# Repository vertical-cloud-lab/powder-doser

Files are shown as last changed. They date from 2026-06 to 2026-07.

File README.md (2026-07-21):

# powder-excavator

A pure-mechanical, gantry-mounted "ladle / trough" for picking up loose
powder from a bed and depositing it at a target location. The trough is
suspended between two vertical arms that grip its **two short end caps**;
a single **longitudinal pivot pin** runs through both end caps along the
trough's long axis L. There are no actuators on the bucket itself — the
gantry's existing X / Z motion plus a fixed wall-/post-mounted **smooth
inclined cam ramp** does all the work.

> **Geometry note (post-review).** An earlier revision of this design used
> a **transverse** pivot pin (running across the trough's width D) and
> tipped the trough **end-over-end** against a **sawtooth** ledge. Both
> choices were retired after a high-effort review by Edison Scientific
> identified (i) a kinematic impossibility — a fixed sawtooth tooth
> cannot engage a fixed-radius hook on a horizontally-translating pivot
> without the lip plunging through the tooth — and (ii) a severe trapped-
> volume / arching problem when cohesive powders are forced to bottleneck
> through the narrow ~13 mm spill point of an end-over-end half-cylinder.
> The current design uses a **longitudinal** pivot pin and **sideways
> tilt** so powder pours over the full 80 mm long edge, and replaces the
> sawtooth with a **smooth cam ramp** that the trough's chamfered bumper
> slides up. A follow-on hand sketch
> ([`PXL_20260423_231729467.jpg`](PXL_20260423_231729467.jpg)) refines the
> cam ramp into a **pin-defined-path** (peg-in-routed-slot) variant in
> which a peg on a stem hanging from the gantry is captured in a slot
> routed into a fixed external board, so the slot path deterministically
> programs the trough's tilt schedule. The full review and the verbatim
> Edison answers live in [`docs/edison/`](docs/edison/); the
> literature-aware brainstorming doc has been ported to a LaTeX manuscript
> with a proper BibTeX bibliography (see
> [`docs/manuscript/main.tex`](docs/manuscript/main.tex) and
> [`docs/manuscript/refs.bib`](docs/manuscript/refs.bib); build with
> `cd docs/manuscript && make`).

## Original concept sketch

Design sketch

## Hardware

Candidate parts for the auger drive motor, vibration motor, external
solenoid, and the Raspberry Pi Zero 2 W driver boards needed to
control them are documented in
[`hardware/vibration-motor-and-solenoid.md`](hardware/vibration-motor-and-solenoid.md).
## Cleaned-up design diagram

The sketch above has been recreated as four labelled subpanels. Each is a
self-contained SVG with its own caption. All four are produced (along with
the mechanism animation below) by a single reproducible script,
[`scripts/generate_figures.py`](scripts/generate_figures.py).

### Panel A — Orthographic views (end / side / top)

Panel A — orthographic

### Panel B — End-cap pivot detail

Panel B — pivot detail

### Panel C — 3D / isometric view of trough on gantry

Panel C — isometric

### Panel D — Mechanism of action (4 steps)

Panel D — mechanism of action

### Panel E — Pin-defined-path actuation variant

A follow-on hand sketch
([`PXL_20260423_231729467.jpg`](PXL_20260423_231729467.jpg)) refines the
smooth cam ramp into a peg-in-routed-slot mechanism. A vertical stem hangs
from the gantry carriage on a pin pivot; a transverse peg at the top of the
stem rides in a slot routed into a fixed external board. The slot's shape
over `X` deterministically programs the trough's tilt schedule, with the peg
captive in the slot for the entire stroke (no approach-and-contact
ambiguity, and bidirectional return without relying on gravity). See
[`docs/manuscript/main.tex`](docs/manuscript/main.tex) §"Pin-defined-path
actuation" for the full trade-off discussion.

Panel E — pin-defined-path actuation

### Animation — cam-engagement and sideways tilt

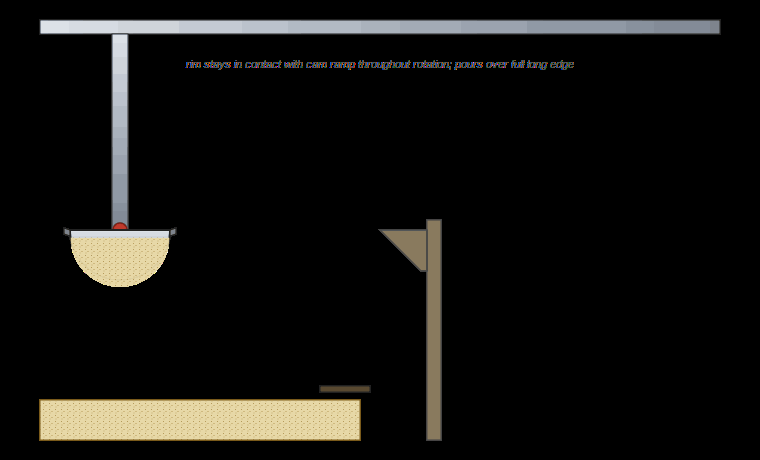
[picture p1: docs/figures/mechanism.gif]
Mechanism animation — trough rolls sideways about its longitudinal pin as its bumper rides up the cam ramp


The full literature-aware design discussion — framed roughly as the
introduction to a *Digital Discovery* manuscript on a new powder
dispenser, with references to recent SDL / powder-handling literature —
is now a LaTeX manuscript with a proper BibTeX bibliography:
[`docs/manuscript/main.tex`](docs/manuscript/main.tex),
[`docs/manuscript/refs.bib`](docs/manuscript/refs.bib). Build with
`cd docs/manuscript && make` (requires `pdflatex`, `bibtex`, and
`cairosvg`).

## Parametric CAD pipeline ([`cad/`](cad/))

The same dimensions used in the figures and the manuscript also drive an
**open, scriptable parametric CAD model** built on
[CadQuery](https://github.com/CadQuery/cadquery), so the design can be
iterated as plain Python source and exported to STEP / STL for any
open-source slicer. A small `cad/dfm.py` runs design-for-manufacturing and
**gantry-only kinematics** checks (the explicit constraint from PR comment
4166621470 — "we have a gantry system and would like to avoid installing a
second axis"), so a parameter regression is caught the next time anyone
edits `ExcavatorParams`. See [`cad/README.md`](cad/README.md) for the
rationale (why CadQuery over Rhino / Grasshopper / Fusion / nTop), the
**target-hardware-matched toolchain** for the **Genmitsu 3018-Pro V2**
(GRBL CNC) and **Prusa MK3 / Ender** (FDM) printers we plan to use, and
the full feedback-loop description.

```bash
pip install cadquery
python -m cad.build      # writes STEP + STL + manifest into cad/build/
python -m cad.dfm        # design-for-manufacturing + gantry-only kinematics checks
python -m unittest discover cad/tests -v
```

## Design brainstorming

### Core idea

The bucket is an **elongated half-cylinder trough** (think: a long,
narrow ladle with a semicircular cross-section and an open top). It is
suspended between **two parallel vertical arms** that hang from the
gantry carriage and grip the trough on its **two short end caps**. A
**single horizontal pivot pin** runs from one arm, through a printed
boss in the first end cap, lengthwise along L through the trough, out
through a matching boss in the second end cap, and into the second arm
(panels B and C). The pivot axis is therefore **parallel to the
trough's long axis L** — the trough rolls about that axis like a
spit-roast rotating about its skewer.

- The two arms are rigidly bolted to the carriage and **always stay
  vertical** during operation.
- The trough is the **only** part that ever rotates, and only about the
  longitudinal pin — rolling **sideways** when its rim-mounted bumper
  catches the cam ramp. Powder pours over the **full 80 mm long edge**,
  not through a narrow end-cap point.
- The pin sits a few millimetres above the loaded trough's centre of
  mass, so gravity returns the trough to "open-up" once the dump cam is
  cleared (a stable pendulum / gondola-style pivot).

Picking shape matters:

- A **half-cylinder** maximises retained volume per unit "scoop depth"
  while presenting a long flat top edge that pours uniformly along its
  whole length.
- An **elongated** trough (length L ≈ 3 × diameter D) gives the spill
  edge a large area (≈ L × few-mm depth) so cohesive powders cannot
  arch across it, eliminating the bottleneck/bridging failure mode of
  an end-over-end tilt of the same trough (Edison v2 §3).
- **No moving lid / hinge in the baseline design** — powder is held in
  by gravity alone, which keeps the part count and the failure modes to
  a minimum.

### Mechanism of action (4 steps — see Panel D)

1. **J-curve plunge into the bed.** The gantry lowers the carriage
   (Z↓) so the trough enters the powder bed, then translates a few
   millimetres in X while continuing down — a shallow J-curve rather
   than a pure Z-plunge. A blunt flat half-cylinder driven straight
   down compresses the bed underneath it instead of flowing in (Edison
   v1 §2); the J-curve lets powder spill into the open top as the
   bucket sweeps forward.
2. **Lift past the strike-off bar.** The carriage rises (Z↑) along an
   X-coordinate that takes the rim of the trough **under a fixed bed-
   edge strike-off bar**. The bar wipes the heaped powder back into the
   bed and leaves a defined fill volume. Without this step, dose CV
   sits in the 15–30 % range across powder classes (Edison v2 §4); with
   it, ≈10 % CV is realistic on cohesive inorganics — comparable to the
   positive-displacement-pipette baseline reported by Alsenz (see
   [`docs/manuscript/main.tex`](docs/manuscript/main.tex)).
3. **Transport to the deposit X.** The carriage translates in X over to
   the deposit station. Arms still vertical; trough still open-up,
   level under gravity.
4. **Sideways tilt against the cam → deposit.** The gantry pushes the
   trough in X into a fixed, wall-/post-mounted **smooth inclined cam
   ramp** at end-cap-rim height. The chamfered bumper on the trough's
   long-side rim **slides up the cam's hypotenuse**; because the cam
   surface is a continuous incline rather than a fixed point, pure-X
   gantry travel is geometrically compatible with the resulting roll of
   the trough about its longitudinal pin (Edison v2 §1). Continued
   X-push rolls the trough sideways and powder pours over the **full
   long edge**. Backing the carriage off lets gravity right the trough
   under its pendulum action.

The "push against a cam to dump" trick is what makes this fully
mechanical — no servo / solenoid is needed on the bucket itself.

### What is the cam ramp?

A **fixed, wall- or post-mounted inclined block** at roughly trough-
end-cap-rim height (see Panel D, Step 4, and the GIF above). Its top
surface is a **smooth ramp** (a chamfered, ideally polished
hypotenuse), *not* a comb of teeth. It is *not* on the floor of the
powder bed and is *not* part of the moving assembly. The trough's rim
bumper rides up the ramp as the gantry pushes the carriage in X; the
height the bumper reaches up the ramp (set by how far in X the gantry
pushes) determines the tilt angle and therefore how much powder is
poured.

Why a smooth ramp and not a sawtooth?

- **Kinematic compatibility.** A fixed sawtooth tooth cannot engage a
  fixed-radius hook on a horizontally-translating pivot pin without the
  lip having to plunge through the tooth — the pin-to-tooth distance
  must change as the pivot moves in X, but the hook's radius is fixed.
  An inclined cam removes the constraint entirely: the contact point
  slides continuously along the cam surface as the gantry travels
  (Edison v2 §1).
- **Continuous tilt control.** With a smooth ramp, the tilt angle is a
  continuous function of gantry X position, so pour rate and final
  dose can be modulated in software without changing hardware.
- **No catch-and-skip failure mode.** A printed sawtooth tooth and a
  printed hook can mis-engage, snag, or skip; a chamfered bumper on a
  smooth incline cannot.

### Optional: knock-to-de-bridge

Because the bumper is in continuous frictional contact with the cam
during the tilt, the gantry can be driven to **rapidly oscillate ±2 mm
in X** while the bumper is engaged. This momentarily slams the trough
against the cam and acts as a free pneumatic-knocker analogue to break
up bridges of cohesive powder that would otherwise refuse to pour
(Edison v1 §6). It is a software-only feature — the same hardware that
performs the tilt also performs the knock.

### Open questions / things to prototype

- **Manufacturing.** Target is a **3D-printable** trough + arms + end-
  cap pivot bosses (PETG / nylon for the prototype, with a glued-in
  brass sleeve for the pin holes if wear becomes an issue). The pivot
  pin itself is a stock dowel pin or shoulder bolt, ideally **metal**
  so it can also serve as the ground path for an optional conductive
  trough lining (e.g. interior copper tape) that mitigates triboelectric
  charging on fine dry inorganics (Edison v1 §2). The cam ramp can be
  printed too. A machined-aluminium revision would only be needed if
  the printed parts wear or charge problematically.
- **Target powders are dozens-of-microns in diameter** — catalysts,
  ceramics, salts. Many are cohesive, hygroscopic, and/or
  triboelectrically charged; some clump and resist removal from a
  scoop. This drives several of the open questions below.
- **Trough geometry sweep.** Pure semicircle vs. a slightly deeper "U"
  vs. a V-bottom — which retains powder best while still pouring
  cleanly when rolled? A 3D-printed bake-off across our worst-case
  cohesive powders is cheap.
- **Cam-ramp angle sweep.** Cam slope, length, and surface finish are
  the three knobs most likely to dominate dose CV. Steeper slopes give
  more aggressive tilts per unit gantry travel but risk bumper slip;
  shallower slopes give finer control but a longer dump stroke.
- **Strike-off bar profile.** Square cross-section vs. a chamfered or
  rounded leading edge — which leaves the cleanest fill at the rim
  without flicking powder away? Worth varying.
- **Bumper profile.** Chamfer angle and surface finish on the rim
  bumper directly affect cam engagement; too sharp and it digs in,
  too rounded and it slips. Print + sand a small set and characterise.
- **Bed depletion.** Repeated scoops from the same X, Y in a static
  bed will form a crater and the dose will decay (Edison v1 §3). The
  gantry must raster the plunge X, Y across the bed, or a separate
  "bed-stir" cycle must be added.
- **Cleaning / cross-contamination.** For multi-material campaigns the
  pivot pin is the natural quick-release point — pull the pin, swap the
  trough, re-insert. For very sticky powders a **per-material
  consumable trough** (snap-in printed liner) may be cheaper than
  cleaning.
- **Use-environment caveat.** A bulk-transfer scoop unavoidably
  exposes the powder to ambient air during transport and leaves an
  open crater in the stock bed. For hygroscopic salts this is a real
  limitation; the device's intended envelope is **bulk transfer in
  ambient or globally-controlled environments (e.g. inside a glovebox
  or on a benchtop with a desiccated stock container)**, not as a
  direct loader for highly moisture-sensitive workflows.

### Possible variations (all still pure-mechanical)

- **Reversible tilt** — cam ramps on both sides of the work area let
  the same bucket dump left or right by which way it's pushed.
- **Two troughs back-to-back** — one fills while the other is being
  dumped, doubling throughput with no extra actuators.
- **Auger / screw inside the trough** — adds one rotary actuator but
  gives controlled metered dosing instead of "tilt and pour all".
- **Passive flap lid for fine powders.** A lightweight flap hinged on
  the trough's long upper edge that gravity holds *closed* over the
  mouth while the trough hangs open-up (so fluffy powder is not shed
  during X-travel). When the trough rolls against the cam ramp in
  step 4, a small projection on the flap strikes a separate fixed tang
  on the same cam assembly, swinging the flap clear so powder can
  pour out. Returns to closed under gravity once the trough returns
  upright. Still purely mechanical — no actuator on the bucket.

### Acknowledgements

The design changes between PR #2 and the present revision were prompted
by a high-effort design review from [Edison Scientific](https://edisonscientific.com/),
plus a literature search via the same service. Verbatim responses are
archived under [`docs/edison/`](docs/edison/) for traceability.
[Presentation at POSE 2026](https://docs.google.com/presentation/d/1SZyMInTeK6V5QMu_9ptvdzXFou06gq9Mr7xBxdh9StA/edit?usp=sharing)

Design sketch

## Design

A written brainstorming pass over candidate dispenser architectures —
parallel-channel, cartridge carousel, X-Y gantry, vibratory, pneumatic,
and shared-auger-with-purge — with the benefits and pitfalls of each
under the autonomous-loop / 30-powder requirements is in
[`design/brainstorming.md`](design/brainstorming.md). No CAD or sketches
are produced at this stage; that document is the output of the
brainstorming session called for in the corresponding tracking issue.
## Candidate powders

The set of metal powders we intend to dispense (high-purity Si,
AlSi10Mg, and the broader BYU VCL digital-alloy-lab element
palette), together with handling/storage constraints and the
custom-Al-crucible dispensing targets, is documented in
[`docs/candidate-powders.md`](docs/candidate-powders.md).

## Paper

A bare-bones LaTeX template in the Digital Discovery (Royal Society of
Chemistry) submission style is available in [`paper/`](paper). It is built on
the official RSC "Paper" article template (two-column, 9 pt Times,
`natbib`/`rsc.bst` bibliography, RSC running headers/footers) and uses
`lipsum` placeholder text. A pre-built PDF is committed alongside it at
[`paper/main.pdf`](paper/main.pdf).

To rebuild the PDF locally you need a TeX Live installation that includes
`latexmk` plus the standard packages used by the template (`natbib`,
`mhchem`, `balance`, `caption`, `fancyhdr`, `lastpage`, `lipsum`,
`url`, `times`/`mathptmx`, `extsizes`). On Debian/Ubuntu these are provided
by `texlive-latex-recommended`, `texlive-latex-extra`,
`texlive-fonts-recommended`, `texlive-science`, and `latexmk`. Only the
RSC-specific assets (`rsc.bst`, `rsc.bib`, `headers/`) are vendored in
`paper/`; all other packages are taken from the system TeX distribution.

```sh
cd paper
latexmk -pdf main.tex
```

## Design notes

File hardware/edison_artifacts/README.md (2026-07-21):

# Edison Scientific artifacts (hardware review)

This directory holds the artifacts returned by an Edison Scientific
ANALYSIS run against the hardware identification + KiCad schematic package
in this PR. The runner is `edison_run_hardware_review.py`, which uploads
the relevant files (`hardware/vibration-motor-and-solenoid.md`, the KiCad
schematic + render + custom symbol library, and the KiCad README) and then
submits an `ANALYSIS` task with the prompt embedded verbatim in the script.

Outputs follow the same per-key triplet convention as
`paper/background/edison_artifacts/`:

* `<key>.task.json` — full task object returned by the Edison API.
* `<key>.answer.md` — the assistant's answer in markdown.
* `<key>.references.md` — formatted answer / references / citations if the
  API populated any.

Re-running the runner requires `EDISON_API_KEY` to be set in the
environment.

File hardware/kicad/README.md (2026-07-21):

# KiCad project — powder-doser actuator stack

This directory contains the electrical schematic for the actuators
documented in [`../vibration-motor-and-solenoid.md`](../vibration-motor-and-solenoid.md):

* `powder_doser_actuators.kicad_pro` — KiCad 7 project file.
* `powder_doser_actuators.kicad_sch` — schematic.
* `powder_doser.kicad_sym` — local symbol library containing the four
  custom block symbols used for boards with no first-party KiCad
  symbol available (see "Placeholder symbols" below).
* `sym-lib-table` — points the project at `powder_doser.kicad_sym`.
* `powder_doser_actuators.svg`, `.png`, `.pdf` — rendered exports
  produced by `kicad-cli sch export {svg,pdf} …` and
  `rsvg-convert`. The PNG is the one embedded in
  [`../vibration-motor-and-solenoid.md`](../vibration-motor-and-solenoid.md).

Open the project with `kicad powder_doser_actuators.kicad_pro` (KiCad 7
or newer).

## How connectivity is expressed

The schematic uses **global net labels** rather than drawn wires.
KiCad treats two pins with identical net-label strings as
electrically connected, regardless of where they are on the sheet.
This keeps the layout legible while still producing an ERC-clean
schematic that can drive a netlist export. Power nets (`+3V3`,
`+5V`, `+12V`, `GND`) and signal nets (`I2C_SDA`, `I2C_SCL`,
`PI_GPIO16`, `PI_GPIO18`, `PI_GPIO20`, `PI_GPIO21`, `ERM_PLUS`,
`ERM_MINUS`, `SOL_A`, `SOL_B`, `STEP_A1/A2/B1/B2`) all use this
convention.

## Symbols used

### From the stock KiCad-7 libraries (`/usr/share/kicad/symbols/`)

| Symbol | Used for |
|---|---|
| `Connector:Barrel_Jack` | 5 V and 12 V external supply inputs (J2, J3) |
| `Device:C_Polarized` | 100 µF / 10 V (C1) and 100 µF / 25 V (C2) bulk caps |
| `Device:L` | JF-0530B solenoid coil (L1) — represented as a plain inductor since the coil's external behaviour is just inductance |
| `Motor:Motor_DC` | ERM coin / LRA vibration motor (M1) |
| `Motor:Stepper_Motor_bipolar` | NEMA 11 bipolar stepper (M2) |
| `power:+3V3`, `+5V`, `+12V`, `GND` | Power-net flags (referenced via labels) |

### Custom block symbols (in `powder_doser.kicad_sym`)

These are simple labelled rectangles with the board's actual
pinout, used **as placeholders** because no first-party
Adafruit / Pololu KiCad library exists at the time of writing:

| Symbol | Refers to |
|---|---|
| `powder_doser:Adafruit_DRV2605L` | Adafruit DRV2605L haptic-driver breakout — [Adafruit #2305](https://www.adafruit.com/product/2305) |
| `powder_doser:Adafruit_DRV8871` | Adafruit DRV8871 H-bridge breakout — [Adafruit #3190](https://www.adafruit.com/product/3190) |
| `powder_doser:Pololu_DRV8825_Carrier` | Pololu DRV8825 stepper-driver carrier — [Pololu #2133](https://www.pololu.com/product/2133) |
| `powder_doser:Adafruit_PermaProto_Bonnet_Pi_Header` | Pi 2×20 GPIO header on the Adafruit Perma-Proto Bonnet Mini — [Adafruit #2310](https://www.adafruit.com/product/2310). Only the pins this project actually uses are exposed on the symbol; the other ~30 GPIOs on the bonnet are passed through unchanged. |

If the BYU PSC has any of these boards already in a vetted local
KiCad library, swap the `powder_doser:*` `lib_id` references in
`powder_doser_actuators.kicad_sch` for the real ones — the net
names will still match.

## Components / connections that need a human to confirm

Per the review feedback ("Don't assume connections you don't know,
instead make note of them and tell me so I can put them in this
repository and clarify where needed"):

1. **Stepper coil pairings.** The schematic ties net labels
   `STEP_A1`/`STEP_A2`/`STEP_B1`/`STEP_B2` to both the DRV8825's
   coil-output pins and the bipolar-stepper symbol's four pins, but
   the *physical* wire colour ↔ coil mapping varies by NEMA-11 SKU
   and must be read from the chosen motor's datasheet (or
   identified with a multimeter on the resistance check) before
   wiring.
2. **Solenoid coil polarity.** The JF-0530B is driven by the
   DRV8871 in single-direction PWM "tap" mode (IN2 tied to GND);
   coil polarity is irrelevant in that mode. If a future revision
   wants bidirectional drive (e.g. active push *and* return), this
   needs to be re-evaluated.
3. **NEMA-11 mounting bracket.** The schematic captures only the
   electrical interface; the mechanical bracket that holds the
   stepper coaxial with the auger shaft is in `cad/`, not here.
4. **Common ground.** The schematic shows the 5 V supply, 12 V
   supply, and Pi all sharing `GND`, but on the Perma-Proto Bonnet
   that is a single physical net only if the two barrel-jack `−`
   terminals are explicitly tied to a Pi `GND` pad — call this out
   in the build instructions.
5. **Footprints / PCB layout.** This project ships a schematic
   only; no `.kicad_pcb` is included because the actuator stack
   sits on a hand-soldered Perma-Proto Bonnet rather than a
   custom-fab PCB.
6. **Single-supply variant not drawn.** The schematic shows the
   "two PSUs" wiring (J2 = 5 V jack, J3 = 12 V jack). The
   recommended **single-supply variant** described in
   `../vibration-motor-and-solenoid.md` ("Power supply" section)
   replaces J2 with a Pololu D24V22F5 buck converter whose `VIN`
   ties to the same `+12V` net as `VMOT` and whose `VOUT`
   becomes the `+5V` net feeding the DRV8871 `VM` and the Pi
   5 V rail. All net labels stay the same; only the source of
   the `+5V` net changes.

## Regenerating the PNG/PDF/SVG exports

The checked-in `.kicad_sch` is the source of truth; the rendered
exports next to it are produced from it with `kicad-cli`. To
regenerate them after editing the schematic in KiCad:

```bash
sudo apt-get install -y kicad librsvg2-bin
cd hardware/kicad
kicad-cli sch export svg powder_doser_actuators.kicad_sch -o ./
kicad-cli sch export pdf powder_doser_actuators.kicad_sch -o powder_doser_actuators.pdf
rsvg-convert -o powder_doser_actuators.png powder_doser_actuators.svg
```

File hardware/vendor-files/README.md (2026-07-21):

# Vendor CAD / PCB / design files

Vendor-published mechanical (CAD) and electrical (PCB) design files for
the parts in the BOM at
[`../vibration-motor-and-solenoid.md`](../vibration-motor-and-solenoid.md).
Each part has its own subdirectory with the upstream files and the
license shipped alongside them.

When a vendor doesn't publish design files (or only ships them behind a
form / login), the entry below has a **manual-download link** instead so
you can grab it yourself.

## Index (BOM order)

| BOM | Part | Vendor | Local files | Manual link(s) |
|-----|---|---|---|---|
| 1 | DRV2605L Haptic Motor Controller breakout | Adafruit #2305 | [`adafruit-2305-drv2605l/`](adafruit-2305-drv2605l/) — `.f3d`/`.step`/`.stl` mechanical (MIT) + Eagle `.brd`/`.sch` PCB (CC BY-SA 3.0) | — |
| 2 | Vibrating Mini Motor Disc — ERM coin (10 mm × 2.7 mm, 3 V) | Adafruit #1201 | _(not in upstream `Adafruit_CAD_Parts`; commodity ERM, no published CAD)_ | [Datasheet PDF on product page](https://www.adafruit.com/product/1201) |
| 3 | LRA (linear resonant actuator) — discontinued #1631 | Precision Microdrives | _(category page only — pick a specific LRA before fetching its STEP)_ | [precisionmicrodrives.com/lras](https://www.precisionmicrodrives.com/product-category/lras) |
| 4 | JF-0530B 5 V mini push–pull solenoid | Adafruit #412 | [`adafruit-412-jf-0530b-solenoid/`](adafruit-412-jf-0530b-solenoid/) — manufacturer mechanical / coil datasheets + solenoid-driver app note (PDFs from the product Resources tab). No upstream CAD. | [Product page](https://www.adafruit.com/product/412) |
| 5 | DRV8871 DC Motor Driver Breakout | Adafruit #3190 | [`adafruit-3190-drv8871/`](adafruit-3190-drv8871/) — `.f3d`/`.step`/`.stl` mechanical (MIT) + Eagle `.brd`/`.sch` PCB (CC BY-SA 3.0) | — |
| 6 | Perma-Proto Bonnet Mini Kit for Pi | Adafruit #2310 | [`adafruit-2310-perma-proto-bonnet/`](adafruit-2310-perma-proto-bonnet/) — Eagle `.brd`/`.sch` PCB (CC BY-SA 3.0) + supplemental HaD Proto HAT Eagle source + Fritzing `.fzpz` + [`SPECS.md`](adafruit-2310-perma-proto-bonnet/SPECS.md) (header / PCB dimensions). Mechanical CAD not in upstream `Adafruit_CAD_Parts`. | [Product page](https://www.adafruit.com/product/2310) |
| 8 | 2.1 mm DC barrel-jack breakout | Adafruit #373 | [`adafruit-373-barrel-jack/`](adafruit-373-barrel-jack/) — manufacturer datasheet PDF for the 2.1 × 5.5 mm jack. No upstream CAD. | [Product page](https://www.adafruit.com/product/373) |
| 10 | NEMA 11 bipolar stepper, 11HS18-0674S | StepperOnline | [`stepperonline-11hs18-0674s/`](stepperonline-11hs18-0674s/) — vendor STEP + dimension SVG + full datasheet + torque curve PDF + [`SPECS.md`](stepperonline-11hs18-0674s/SPECS.md). Files were downloaded manually from the product Resources tab (StepperOnline blocks direct curl). | [Product page → "3D Models" / "Drawing" / "Datasheet" tabs](https://www.omc-stepperonline.com/nema-11-bipolar-1-8deg-10ncm-14-16oz-in-0-67a-28x28x45mm-4-wires-11hs18-0674s) |
| 11 | Tic T500 USB Multi-Interface Stepper Motor Controller | Pololu #3135 | [`pololu-3135-tic-t500/`](pololu-3135-tic-t500/) — vendor STEP/STL ZIP (`cad/tic-stepper-motor-controller-models.zip`), drill-guide + dimension PDFs (`dimensions/`), Tic user guide (`datasheets/tic.pdf`). | [Product Resources tab](https://www.pololu.com/product/3135/resources) |
| 11-alt | DRV8825 Stepper Motor Driver Carrier, High Current | Pololu #2133 | [`pololu-2133-drv8825/`](pololu-2133-drv8825/) — vendor STEP (`cad/`), drill-guide + dimension PDFs + DXF (`dimensions/`), schematic PDF (`datasheets/`). | [Product Resources tab](https://www.pololu.com/product/2133/resources) |
| 12 | 5 mm ↔ 5 mm aluminum flexible shaft coupler ST-FC01 | StepperOnline | [`stepperonline-st-fc01-coupler/SPECS.md`](stepperonline-st-fc01-coupler/SPECS.md) — text spec only (StepperOnline does not publish a STEP for this part). | [Product page → "Drawing" tab](https://www.omc-stepperonline.com/5mm-5mm-flexible-shaft-coupling-18x25mm-cnc-stepper-motor-shaft-coupler-st-fc01) |
| 13 | 12 V / 5 A switching power supply (Mean Well GST60A12-P1J) | Mean Well via Digi-Key | _(commodity desktop brick; no published CAD)_ | [Digi-Key product page](https://www.digikey.com/en/products/detail/mean-well-usa-inc/GST60A12-P1J/7702675) |
| 13b | 2.1 × 5.5 mm DC barrel-jack-to-screw-terminal pigtail | CUI / Switchcraft via Digi-Key | [`digikey-barrel-jack-pigtail/`](digikey-barrel-jack-pigtail/) — CUI P1012-family datasheet PDF. | [Digi-Key barrel-jack adapter family](https://www.digikey.com/en/products/filter/dc-power-connectors/445) |
| 15 | D24V22F5 5 V / 2.5 A step-down regulator | Pololu #2858 | [`pololu-2858-d24v22f5/`](pololu-2858-d24v22f5/) — vendor STEP (`cad/`), drill-guide DXF + dimension PDF (`dimensions/`). | [Product Resources tab](https://www.pololu.com/product/2858/resources) |
| 16 | Standard-size High-Torque Metal-Gear digital servo (HD-1810MG) | Adafruit #1142 | [`adafruit-1142-metal-gear-servo/SPECS.md`](adafruit-1142-metal-gear-servo/SPECS.md) — text spec only (not in upstream `Adafruit_CAD_Parts`). | [Product page](https://www.adafruit.com/product/1142) — see also the closely-related Adafruit [#1143 STEP/STL in `Adafruit_CAD_Parts`](https://github.com/adafruit/Adafruit_CAD_Parts/tree/master/1143%20Micro%20Servo%20-%20High%20Torque%20Metal%20Gear) for envelope reference |
| 16-alt | SG-92R micro-servo | Adafruit #169 | _(not in upstream `Adafruit_CAD_Parts`)_ | [Product page](https://www.adafruit.com/product/169) — Adafruit [#2201 sub-micro STEP](https://github.com/adafruit/Adafruit_CAD_Parts/tree/master/2201%20Submicro%20servo) is an OK envelope proxy |
| 17 | M2/M3 servo-mount screws + horn | from #1142 accessory bag | — | (ships with the servo) |
| 18 | 33 V / 9 W shunt regulator | Pololu #3776 | [`pololu-3776-shunt-regulator-9w/`](pololu-3776-shunt-regulator-9w/) — vendor STEP (`cad/`), drill-guide DXFs + dimension PDF (`dimensions/`). | [Product Resources tab](https://www.pololu.com/product/3776/resources) |
| — | Pi Zero 2 W | Adafruit #5291 / Raspberry Pi | [`raspberry-pi-zero-2-w/`](raspberry-pi-zero-2-w/) — official mechanical drawing PDF (`dimensions/`) and product brief (`datasheets/`). | [Raspberry Pi mechanical drawing PDF](https://datasheets.raspberrypi.com/pizero2/pi-zero-2-w-mechanical-drawing.pdf) |
| — | Mini aluminum heat sink (13 × 13 × 3 mm) | Adafruit #3084 | _(commodity finned heat sink; no upstream CAD)_ | [Product page](https://www.adafruit.com/product/3084) |
| — | 16 GB Class-10 microSD with adapter | Adafruit #2693 | _(commodity SD card; no published CAD)_ | [Product page](https://www.adafruit.com/product/2693) |
| — | 5 V / 2.4 A USB power supply (micro-USB) | Adafruit #1995 | _(generic wall-wart; no published CAD)_ | [Product page](https://www.adafruit.com/product/1995) |

## Licenses

* Files copied from [`adafruit/Adafruit_CAD_Parts`](https://github.com/adafruit/Adafruit_CAD_Parts)
  ship under the **MIT License** (`LICENSE` next to each `cad/` folder).
* Files copied from `adafruit/Adafruit-*-PCB` repositories ship under
  **Creative Commons Attribution-ShareAlike 3.0 Unported** (CC BY-SA 3.0,
  `LICENSE.txt` next to each `pcb/` folder).
* Pololu drill-guide PDFs/DXFs are reproduced verbatim from the
  product-page "Resources" tab; redistribution rights follow Pololu's
  posted [terms of use](https://www.pololu.com/about/copyright). They
  are included here as engineering references, not as design originals.

## How these were fetched

```bash
# Adafruit mechanical CAD (sparse-checkout to keep the clone small)
git clone --depth 1 --filter=blob:none --sparse \
    https://github.com/adafruit/Adafruit_CAD_Parts.git
cd Adafruit_CAD_Parts
git sparse-checkout set "2305 DRV2605L" "3190 DRV8871 Breakout"

# Adafruit PCB sources
git clone --depth 1 https://github.com/adafruit/Adafruit-DRV2605-PCB.git
git clone --depth 1 https://github.com/adafruit/Adafruit-DRV8871-Breakout-PCB.git
git clone --depth 1 https://github.com/adafruit/Adafruit-Perma-Proto-Bonnet-PCB.git

# Pololu drill guides (direct from product-page Resources tab)
curl -O https://www.pololu.com/file/0J1428/tic-t500-drill-guide.pdf            # #3135
curl -O https://www.pololu.com/file/0J590/drv8825-dimensions.pdf               # #2133
curl -O https://www.pololu.com/file/0J1042/d24v22f5-drill-guide.dxf            # #2858
curl -O https://www.pololu.com/file/0J1814/shunt-regulator-9w-drill-guide.dxf  # #3776
```

To refresh, re-run the snippet above and copy the new files over the
ones in this directory.

The remaining files (StepperOnline `11HS18-0674S.*`, the Pololu STEP /
schematic / dimension PDFs, the Adafruit `412_C514-B_diagram.pdf` /
`C514-datasheet.pdf` / `solenoid_driver.pdf`, the Raspberry Pi
mechanical drawing + product brief, the Adafruit HaD Proto HAT Eagle
sources + Fritzing part, the Adafruit `21mmdcjackDatasheet.pdf`, and
the CUI `P1012_datasheet.pdf`) were downloaded manually via a browser
from each part's product / Resources page — see the per-part
`SOURCES.txt` (and, where applicable, `SPECS.md`) inside each
subdirectory for the exact link and any notes on what's inside.

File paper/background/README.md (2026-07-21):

# Background research for the BYU NASA Space Grant proposal

This folder collects literature and landscape reviews to inform the
**background section** of the grant proposal scaffolded under
[`paper/main.tex`](../main.tex) (see issue
[#26](https://github.com/vertical-cloud-lab/powder-doser/issues/26)).

The proposal is framed around generative CAD applied to this repository
(`powder-doser`), tied to a larger vision of autonomous discovery of
additively manufactured (AM) aerospace alloys, where accurate multi-powder
dosing is a critical unmet need. Two background pillars therefore need to be
covered, each addressed by both a *landscape* review (commercial / tool-level
state of the art) and a *literature* review (recent peer-reviewed work):

| File | Pillar | Scope |
| --- | --- | --- |
| [`01-powder-dispensing-commercial-landscape.md`](01-powder-dispensing-commercial-landscape.md) | Powder dispensing | Commercial systems (Mettler Toledo Quantos/CHRONECT, Chemspeed SWING/FLEX, Unchained Labs, Coperion K-Tron, Schenck, Gericke, Brabender, Movacolor, Freeman FT4, Sartorius), accuracy/throughput/price, gap analysis for sub-$10k AM-capable multi-powder dosing. References issue [#10](https://github.com/vertical-cloud-lab/powder-doser/issues/10). |
| [`02-powder-dispensing-academic-literature.md`](02-powder-dispensing-academic-literature.md) | Powder dispensing | Recent (2018–2025) peer-reviewed papers on automated dosing, multi-material/HT metal AM (Ni, Ti, HEAs, refractory alloys), compositionally graded alloy discovery, self-driving labs handling solids, and powder-flowability characterization. |
| [`03-generative-cad-landscape.md`](03-generative-cad-landscape.md) | Generative CAD | Commercial (Fusion Generative Design, nTop, Siemens NX, PTC Creo, ANSYS Discovery, Altair Inspire, Rhino + Grasshopper) and code-based / parametric (CadQuery, OpenSCAD, build123d, Onshape FeatureScript, JSCAD) tools, plus AI/LLM-driven CAD research, with capability and limitation comparisons. References issue [#6](https://github.com/vertical-cloud-lab/powder-doser/issues/6). |
| [`04-generative-cad-academic-literature.md`](04-generative-cad-academic-literature.md) | Generative CAD | Recent (2021–2025) peer-reviewed and arXiv work on generative CAD, AI-assisted CAD, LLM-based CAD code generation, programmatic CAD, and learning-based shape generation, plus landmark datasets (DeepCAD, Fusion 360 Gallery, ABC, SketchGraphs, Text2CAD). |
| [`05-llm-cad-spatial-reasoning-mitigation.md`](05-llm-cad-spatial-reasoning-mitigation.md) | Generative CAD | Synthesis (triggered by [PR #34 comment 4433787200](https://github.com/vertical-cloud-lab/powder-doser/pull/34#issuecomment-4433787200)) on LLM/agent spatial-reasoning + assembly failures observed in [PR #35](https://github.com/vertical-cloud-lab/powder-doser/pull/35) (Claude Opus 4.7 CadQuery), with concrete tool-side / prompting / representation / human-in-the-loop mitigations. Backed by a follow-up Edison `LITERATURE_HIGH` query (see below). |
| [`06-tools-and-repositories-to-try.md`](06-tools-and-repositories-to-try.md) | Both | Synthesis (triggered by [PR #29 comment 4434939162](https://github.com/vertical-cloud-lab/powder-doser/pull/29#issuecomment-4434939162)) re-organising the tools cited across `01`–`05` around what can actually be cloned, installed, or subscribed to today: code-CAD foundations (CadQuery, build123d, OCP, FreeCAD, slicers), 2024–2026 LLM-CAD research repos (CADSmith, CAD-Coder, CAD-Recode, Text-to-CadQuery, CAD-MLLM, CADCrafter, …), datasets, commercial subscriptions worth trialling (Onshape, Zoo.dev) vs. ones to skip on the proposal budget (nTop, Creo, NX), and a 6-step recommended trial set. Connects to [PR #7](https://github.com/vertical-cloud-lab/powder-doser/pull/7)'s open-source CAD tooling work. |

## Provenance

These notes were produced by four parallel
[Edison Scientific](https://edisonscientific.gitbook.io/edison-cookbook)
`LITERATURE_HIGH` queries (the `paperqa`-class deep literature pipeline). Each
claim in the notes is followed by a citation key of the form
`(authorYYYYshortid pages X-Y)`; the corresponding numbered references — with
authors, journal, DOI, and citation count — are listed at the bottom of each
file.

The notes are intentionally kept verbatim (lightly formatted markdown) rather
than paraphrased, so that citation provenance to the underlying sources is
preserved when individual passages are pulled into the LaTeX manuscript.

## How to use these notes when drafting the proposal

1. Skim each file's table of contents (`##` section headings) and the
   *Conclusions / Key takeaways* sections at the end.
2. Pull specific claims into the proposal's Background and Motivation
   sections, replacing the inline `(authorYYYY... pages ...)` Edison citation
   keys with `\cite{...}` calls into [`paper/rsc.bib`](../rsc.bib).
3. For any reference cited in the proposal, copy the corresponding entry from
   the file's *References* section into `paper/rsc.bib` as a proper BibTeX
   entry (the DOI is provided in every Edison reference). Only references
   that are actually cited in the manuscript should end up in `rsc.bib` —
   leave the broader bibliography here in the notes for traceability.
4. The *Technology Gap Analysis* table in
   `01-powder-dispensing-commercial-landscape.md` and the
   *Capabilities vs. Limitations* discussion in
   `03-generative-cad-landscape.md` and
   `04-generative-cad-academic-literature.md` are particularly relevant
   for motivating the proposal's research questions.

## Raw query artifacts (provenance)

The full raw outputs from Edison — including the underlying contexts,
references, agent state, cost, and token counts — are committed under
[`edison_artifacts/`](edison_artifacts/) for reproducibility. Each query has
three files (`<key>.task.json`, `<key>.answer.md`, `<key>.references.md`); see
[`edison_artifacts/README.md`](edison_artifacts/README.md) for layout.

## Reproducing or refreshing the notes

The four original queries can be re-run end-to-end with
[`edison_run.py`](edison_run.py); the follow-up spatial-reasoning query that
backs `05-llm-cad-spatial-reasoning-mitigation.md` lives in
[`edison_run_followup_spatial.py`](edison_run_followup_spatial.py). Both
embed their prompts verbatim and write the artifacts described above:

Both runners read the API key from the `EDISON_API_KEY` environment variable
via `os.environ["EDISON_API_KEY"]` (never hard-coded or logged):

```sh
pip install edison_client
export EDISON_API_KEY=...   # never commit this value
python paper/background/edison_run.py
python paper/background/edison_run_followup_spatial.py
```

A high-effort literature query takes roughly 20–30 minutes per task; all four
are dispatched in parallel via `EdisonClient.run_tasks_until_done`.

The prompts are also quoted verbatim at the top of each `0*-*.md` file (the
`Question:` line), so they can be edited and re-run independently.

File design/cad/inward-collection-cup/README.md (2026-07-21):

# Inward-pointing single-collection-point — visualization

A first-pass visualization of the §2.2 dispense geometry from
[`design/brainstorming.md`](../../brainstorming.md): N parallel auger
channels arranged on a pitch circle, all aimed inward at a single shared
collection cup that sits on a load cell directly below.

Requested by @sgbaird in [PR #31 review comment 4427144685][c]. The intent
of this folder is to make the spatial concept legible (and to sanity-check
the §2.2 dimensions against each other) — *not* to be a manufacturing
package. There is no auger flighting, no motor mounts, no load-cell
flexure, and no bracketing structure here.

[c]: https://github.com/vertical-cloud-lab/powder-doser/pull/31#issuecomment-4427144685

## Files

| File | What it is |
| --- | --- |
| [`sketch_top_side.png`](sketch_top_side.png) | 2D dimensioned schematic (top + side views), generated by [`sketch_2d.py`](sketch_2d.py) using matplotlib. The freeform starting point that @sgbaird asked for. |
| [`inward_collection_cup.step`](inward_collection_cup.step) | Parametric CAD model exported from [`cad_model.py`](cad_model.py) (CadQuery / OpenCascade). Open in FreeCAD / KiCad StepUp / Fusion / SolidWorks. |
| [`inward_collection_cup_iso.svg`](inward_collection_cup_iso.svg) / [`.png`](inward_collection_cup_iso.png) | Isometric line render of the STEP model. |
| [`inward_collection_cup_top.svg`](inward_collection_cup_top.svg) / [`.png`](inward_collection_cup_top.png) | Top-down line render of the STEP model. |

## Geometry (single source of truth)

Both scripts share the same constants. Numbers come from §2.2 of
`brainstorming.md`; "~" values there are pinned to round numbers here:

| Parameter | Value | Notes |
| --- | --- | ---: |
| Number of channels `N` | 12 | §1 "loaded subset of ~8–12" |
| Auger tube OD / bore | 30 mm / 12 mm | §2.2 "~30 mm-diameter tubes" |
| Tube length (visible) | 110 mm | schematic only |
| Pitch circle diameter | 150 mm | §2.2 "~150 mm pitch circle" |
| Tube tilt from vertical | 30° | aimed inward at cup |
| Outlet height above cup rim | 80 mm | clearance for vibration & swirl |
| Collection cup OD / ID / height | 80 / 70 / 35 mm | §2.2 "~40 mm-radius cup" |
| Hopper / cartridge OD × H | 55 × 70 mm | placeholder for #25-class hopper |
| Load cell footprint × H | 110 × 110 × 18 mm | placeholder envelope |

With these numbers, the 12 ø30 mm tubes have ~9 mm of tangential clearance
between adjacent ODs at the pitch circle, the inner edges of the tubes sit
~20 mm outboard of the cup wall, and the reservoirs above the tubes do not
collide. This is consistent with §2.2's claim that ~12 channels fit
"comfortably" around an 80 mm cup at ~150 mm pitch.

## Reproducing the renders

```bash
cd design/cad/inward-collection-cup
pip install cadquery matplotlib cairosvg
python sketch_2d.py        # writes sketch_top_side.png
python cad_model.py        # writes the STEP and the two SVGs
python -c "import cairosvg; \
  [cairosvg.svg2png(url=f'inward_collection_cup_{v}.svg', \
                    write_to=f'inward_collection_cup_{v}.png', \
                    output_width=1600) for v in ('iso','top')]"
```

## Known limitations / next steps

- The CAD `union()` over 12 tilted tubes is intentionally a single
  combined solid for clean SVG line work; it is **not** a proper
  exploded assembly. For real CAD work, build the channels as
  individual parts in an Assembly.
- No auger flighting: the bore is shown as an empty cylinder.
- No motor / DRV8825 / vibration-actuator placement on top of the
  reservoirs — those would extend further upward than what is drawn.
- The "moving-cup-on-gantry/carousel" variant called out in §2.2 is
  not visualized here; that should be a sibling folder if/when it is
  worked up.
- The CAD's front-elevation view was dropped because the SVG export
  framing was unreadable; the matplotlib `sketch_top_side.png`
  already covers the side view with proper dimensioning.

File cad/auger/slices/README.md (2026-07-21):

# Auger slices (v4 — integrated single-piece rotor, H2D)

The auger is **one printable part** (per PR review reversion of the v3
two-part experiment back to the v1/v2.1 monolithic architecture). It is
sliced for the **Bambu Lab H2D** (build volume 350 × 320 × 325 mm —
the 250 × 25 mm pillar has ~75 mm of Z headroom and fits the bed with
plenty of room for brim and skirt) on 1.75 mm PLA at 0.4 mm nozzle /
0.2 mm layers / 3 perimeters / 40 % gyroid infill / 4 mm brim /
supports at 50°.

## Files

### PrusaSlicer CLI (canonical)

| Printer | G-code | Time | Material |
|---|---|---|---|
| Bambu Lab H2D | [`archimedes-auger.H2D.gcode`](archimedes-auger.H2D.gcode) | ≈ 7 h 31 m | 73.5 cm³ (~92 g) |
| Bambu Lab H2D (USB short name) | [`AUGER.gcode`](AUGER.gcode) | same as above | same as above |

PrusaSlicer's Marlin (legacy) g-code flavour is what the H2D's
RepRap-derived firmware expects once start/end blocks are spelled out
explicitly (the script writes the resolved blocks — no `{placeholder}`
substitution required).

### CuraEngine (Ultimaker Cura's open-source slice engine)

Generated by `slice_cura.sh` when `cura-slicer` is available on the
runner. Same naming pattern with `.cura.gcode` suffix:

```
archimedes-auger.H2D.cura.gcode
```

## Print orientation & supports

Print **exit-hole DOWN on the bed** (Z+ = M3 boss). The 1.5 mm exit hole
sits in the centre of a small annular bed contact — 4 mm brim is enough
adhesion. Supports at 50° handle:
  * the helix's inner-edge bridge above the funnel cavity, and
  * the top cap's boss-to-wall annulus bridge at the very top.

After printing:
  * Tap the M3 spindle hole with an M3 hand tap.
  * If the exit hole comes out tight (< 2.5 mm functional ID), open it
    with a 2.5 mm drill bit.

## Step-by-step on the printer

1. Copy `AUGER.gcode` to the H2D via USB / SD card / cloud upload.
2. Pre-flight: bed levelled, nozzle clean, PLA loaded. The file sets
   PLA 215/215 °C and bed 60 °C in its start block, so don't override
   on the LCD before pressing start.
3. The start block is `G28` → `G1 Z5 F5000`: home, then lift 5 mm, then
   begin layer 1.
4. ≈ 7.5 h print time — start before a workday, finish during.

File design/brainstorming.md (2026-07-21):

# Powder doser — design brainstorming

This document is the written output of the brainstorming session called for
in [issue #29][i29]: an exploration of *architecture-level* design
possibilities for the powder doser, with the benefits and pitfalls of each.
No sketches or CAD are produced here — those are deferred to follow-up
issues once one or two architectures are chosen for prototyping.

[i29]: https://github.com/vertical-cloud-lab/powder-doser/issues/29

## 1. Requirements recap

The targets are pulled from the BYU NASA Space Grant 2026 proposal (PR
[#27][i27]) and the actuator/electronics selection (PR [#25][i25]):

- **Number of powders:** the proposal cites up to 30 distinct feedstocks
  available to the doser, but a *single* aerospace alloy realistically
  draws on only ~8–10 metal powders. Per Will's review of an earlier draft
  of this document, the autonomy budget already includes a per-campaign
  human touch (refill), and that same touch can swap which subset of
  powders is currently loaded. The architecture therefore does **not** have
  to host all 30 powders simultaneously — designs sized for ~8–12 active
  reservoirs with off-line cartridge/hopper storage for the rest are in
  scope and should be preferred where they materially shrink BOM or
  footprint. *However*, per a follow-up note from Sterling on the same
  thread, even before a fully closed autonomous loop is in place there is
  real value in being able to run *back-to-back* blends drawn from a
  larger pool of distinct elements (e.g. picking many different 6-element
  subsets out of 30 in one sitting), so a candidate architecture loses
  points if it can *only* hit ~8–12 channels and has no plausible path
  to growing the addressable element library beyond the currently-loaded
  subset (e.g. via a rack/carousel of swappable cartridges, as in 2.3).
- **Per-blend volume:** ≤ 250 mL of mixed powder per dispense cycle.
- **Per-powder accuracy:** ±1 wt% baseline, ±0.1 wt% stretch goal.
- **Powder family:** L-PBF metal feedstocks (representative candidates: 316L,
  Ti-6Al-4V, IN718) plus, opportunistically, organic/ceramic powders such as
  the xanthan gum used in early POSE testing.
- **Particle-size preservation:** PSD verified by laser diffraction
  pre- vs. post-dose; the dispenser must not appreciably grind, classify, or
  segregate the feedstock.
- **Cross-contamination:** quantified on three representative L-PBF powders;
  must be low enough to be acceptable for downstream alloy-discovery work.
- **Atmosphere:** ambient air for v1; inert-atmosphere enclosure deferred to
  v2 but should not be designed *out* of the v1 architecture.
- **Autonomy:** the doser sits inside an autonomous AM-alloy discovery loop
  feeding ultrasonic atomization → L-PBF, so a human should *not* have to
  swap, clean, or re-tare hardware between blends. A human refilling
  reservoirs once per campaign is acceptable; a human touching the
  dispense path between blends is not.
- **Driver hardware already chosen** (#25): NEMA 11 bipolar stepper on a
  Pololu DRV8825 carrier for the auger drive, JF-0530B solenoid on an
  Adafruit DRV8871, and an ERM/LRA vibration actuator on a DRV2605L, all
  hosted on a Raspberry Pi Zero 2 W via an Adafruit Perma-Proto Bonnet.

[i25]: https://github.com/vertical-cloud-lab/powder-doser/pull/25
[i27]: https://github.com/vertical-cloud-lab/powder-doser/pull/27

The combination of "30 powders" and "no human in the loop between blends"
is what makes this hard: any architecture in which the dispense path is
shared between powders must either tolerate cross-contamination, clean
itself between powders, or physically swap the contaminated parts.

## 1a. Per-channel mechanism stack (Sterling, PR thread)

Independent of architecture, Sterling has called out on the PR thread
that **every powder station should carry all three of the actuators
already selected in #25**, used in combination rather than as
alternatives:

1. **Auger** rotated by the NEMA 11 stepper, for bulk dispense rate.
2. **Tapping** via the JF-0530B solenoid, for breaking initial bridges
   and for the last-few-percent trim dispenses.
3. **Vibration** via the ERM/LRA on the DRV2605L, for sustained flow
   promotion at the auger-tube interface.

Different powders behave very differently — some flow well under
vibration alone, others need percussive taps to start, others need the
auger to do all the work — and the controller is expected to mix and
match these mechanisms per powder. A **fourth, possibly manual,
auger-angle adjustment** is also on Sterling's wish list (some powders
dispense more cleanly off-vertical), so the architecture should at
least not preclude tilting the dispense element.

Two related dispense mechanisms are explicitly **out of scope** per
that same comment:

- **Air-displacement / pneumatic transfer** — safety risk with reactive
  metal powders, plus concerns about over- or under-shooting the
  collection cup. This rules out architecture 2.6 below as a primary
  path; it remains catalogued only for completeness.
- **Mechanical scraping for de-clumping** — the strategy is to prevent
  clumps upstream (manual lump-breaking before loading, room-level
  industrial dehumidifier, inert atmosphere where possible) rather
  than to break them up inside the dispenser.

## 2. Architecture options

For each candidate the discussion flags benefits, pitfalls, and the
specific way it interacts with the autonomy and cross-contamination
requirements. Per §1a, every architecture below assumes the
auger / tap / vibrate triplet is present at each dispense site; the
architectures differ in *how many* dispense sites exist and in
whether any hardware is shared between powders.

### 2.1 Manual single-tube swap (status-quo / strawman — rejected)

A single auger + tube + reservoir; the operator pulls the assembly,
brushes/vacuums it, and reloads with the next powder.

- **Benefits:** simplest mechanically; only one of every actuator from #25
  needs to exist; trivial to validate in isolation.
- **Pitfalls:** breaks the autonomy requirement outright. Listed only as a
  baseline to compare the other options against and to make explicit why
  it is being rejected for the autonomous-loop use case.

### 2.2 N parallel dispense channels — one reservoir + auger per powder

The "obvious" answer: replicate the #25 actuator stack `N` times. Each
powder lives in its own hopper, fed by its own auger tube. The cleanest
physical layout is a fan or ring of channels with their tube outlets
all aimed at a single shared collection cup on a load cell directly
below — i.e. the cup is stationary and the channels surround it. With
~30 mm-diameter tubes, ~12 channels fit on a ~150 mm pitch circle aimed
inward at a ~40 mm-radius cup, so the §1 "loaded subset of ~8–12"
sizing comfortably fits this geometry; supporting all 30 simultaneously
would require either two stacked rings or a much larger cup. As a
variant of this same architecture, the cup + load cell can instead be
moved on a gantry or carousel under each channel in turn (similar to
2.3/2.4 but with the *cup* moving instead of the dispense head); that
removes the fan-in geometry constraint at the cost of motion on the
weighing side, which is the noisier place to put it.

A first-pass visualization of this geometry (2D dimensioned sketch + a
parametric CadQuery STEP model with isometric and top-down line renders)
lives in [`design/cad/inward-collection-cup/`](cad/inward-collection-cup/README.md).

- **Benefits:**
  - Zero cross-contamination by construction — powders never share a
    wetted surface.
  - Channels are embarrassingly parallel: a failed channel doesn't stop
    the others, and channels can dispense in any order, including in
    parallel for very different mass targets. (Per-channel tunability
    of pitch / RPM / vibration profile is *not* unique to 2.2 — 2.3
    and 2.4 can also tune those parameters per cartridge in software,
    Will noted on an earlier draft — so it isn't called out as a
    benefit here.)
  - Cleanest path to the inert-atmosphere v2: the whole bank of channels
    sits inside one sealed enclosure with a single dispense aperture.
- **Pitfalls:**
  - **Footprint and BOM scale linearly with N.** Even at the §1
    "loaded subset" of ~8–12, that is 8–12 NEMA-11 steppers, 8–12
    DRV8825s, 8–12 hoppers, 8–12 augers; at the full 30 it doubles
    again. Mechanical packaging dominates; electronics cost is also
    non-trivial (~$20–$30 per channel before the hopper/auger).
  - Pi I/O fan-out: even 12 step/dir pairs is past what one Pi Zero 2 W
    + bonnet can host without an I²C/SPI GPIO expander or a
    daisy-chainable stepper bus (e.g. TMC stepper drivers on a shared
    UART, or stepper modules behind I²C expanders); 30 makes this
    mandatory.
  - Per-channel calibration burden: each channel needs its own
    flow-rate vs. step-rate model. This is a software problem, not a
    hardware one, but it does scale with N.
  - Dead volume in each hopper: N × (refill threshold) of powder must
    sit on the bench at all times.

This is the option that most cleanly satisfies the requirements as
written, and is the recommended starting point for the prototype.

### 2.3 Carousel of cartridges sharing one dispense head

A single auger/dispense head stays fixed above the collection cup; a
rotating carousel of `N` cartridges (each cartridge = hopper + integrated
auger flight) indexes the next powder under the head, which engages and
drives that cartridge's flight via a flexible coupler or splined shaft.

- **Benefits:**
  - Only **one** stepper, driver, vibration motor, and solenoid — the
    BOM no longer scales with N.
  - Cross-contamination is again zero, because each cartridge contains
    its *own* wetted surfaces (hopper walls + auger flight); the shared
    motor never touches powder.
  - Cartridges become the natural unit of refill and storage: a swappable,
    sealed cartridge can be loaded off-line, weighed, and verified before
    being inserted.
  - Indexing is a single rotational degree of freedom, which is mechanically
    cheap and easy to home/index repeatably (a second small stepper or a
    geared servo with a hall-effect or optical index sensor).
- **Pitfalls:**
  - The shaft-engagement coupling is the hard part: it must transmit
    torque, self-align after every index move, and not generate or
    accumulate powder on the engagement faces. A magnetic / Oldham /
    spring-loaded dog clutch are all candidates and all need prototyping.
    Will flagged this on the PR thread as the single biggest area of
    interest for 2.3 — *if* a simple, consistent coupling can be
    designed, 2.3 (and the 1 × N variant of 2.4 that shares the same
    clutch) becomes a clear v1 candidate; if it can't, the architecture
    falls apart, so this is the highest-priority de-risking task in §4.
  - Cartridges are now a custom mechanical assembly that has to be
    produced in quantity (one per loaded powder, plus spares for
    off-line refills). Will pointed out on an earlier draft that since
    the auger tubes themselves are 3D-printable on the Bambu H2D, full
    cartridges built around those same tubes should print on the same
    machine without much trouble — so this is a fixturing / repeatable-
    geometry task rather than a manufacturing risk.
  - Carousel diameter scales with cartridge cross-section × 30 — at any
    reasonable cartridge size the carousel is large (rough cocktail-napkin
    estimate: a 60 mm-diameter cartridge × 30 → roughly a 600 mm
    pitch-circle carousel). This may push the design toward two stacked
    smaller carousels of 15 each, or toward 2.4.
  - Refill ergonomics: rotating the desired cartridge into a "refill
    position" is straightforward, but the operator now has to know how the
    indexing software sees the carousel.

### 2.4 X-Y / linear gantry over a static cartridge array

A grid (e.g. 5 × 6 = 30) of cartridges, each with its own auger flight
but no motor. A single drive head on an X-Y gantry parks over the
selected cartridge, descends, engages the flight, dispenses, retracts,
and moves to the next one. Variant: a single linear axis over a 1 × 30
strip of cartridges.

- **Benefits:**
  - Same one-motor BOM win as 2.3, with a more compact footprint per
    cartridge (cartridges can be packed tightly because they don't need
    to share an axis of rotation).
  - X-Y gantry mechanics are extremely well understood — every Bambu
    printer in the lab is one — so the motion stage can crib heavily
    from off-the-shelf 3D-printer kinematics.
  - Cartridges can be added, removed, or re-arranged without re-balancing
    a rotating assembly.
- **Pitfalls:**
  - In the X-Y *grid* sub-variant, the dispense head has to *travel
    over* the open tops of other cartridges, so cartridges must be
    sealed (lidded with a self-closing slit) or the gantry must
    dispense outside the cartridge field — otherwise stray powder shed
    from the head will fall into the wrong cartridge. The **1 × N
    linear sub-variant collapses this problem**: with the cartridges in
    a single row and the cup parked off the end of the row, the
    drive-head travel path no longer crosses any cartridge mouth, and
    the architecture reduces to a single motion axis plus the same
    shaft-engagement clutch as 2.3 (Will's note on the original draft).
  - Two motion axes plus a Z-engage axis on the head in the grid
    sub-variant, so its BOM is higher than 2.3; the 1 × N sub-variant
    is closer to 2.3 in BOM.
  - Same shaft-engagement problem as 2.3.

### 2.5 Vibratory / piezo dispensing instead of an auger

Replace the auger with a vibratory trough or piezo-driven dispense
nozzle (one per powder). The vibration motor from #25 already exists;
the piezo variant would replace the DRV2605L + ERM with a piezo driver
and a stack actuator. *(Note: this is the auger-less variant; the
default per-channel mechanism stack from §1a still keeps vibration as a
flow aid alongside the auger in the other architectures.)* On Will's
review of the original draft, the pitfalls below — particularly
powder-dependent throughput and sensitivity to powder height/humidity/
tribocharging — were judged to make this option a poor fit for the
varied L-PBF feedstock list, so it is kept catalogued but not
recommended as a v1 path.

- **Benefits:**
  - No rotating wetted parts at all → very low risk of grinding the
    powder or altering the PSD.
  - Mechanically the simplest possible dispense element — well-suited to
    being mass-produced 30 times for an option-2.2-style channel bank.
  - Naturally bidirectional in throughput: macro-dose with steady
    excitation, then trim with single-pulse "tap" dispenses for the last
    few percent of mass.
- **Pitfalls:**
  - Throughput is powder-dependent and can be very low for cohesive
    metal powders (Ti-6Al-4V is notorious here). Hitting 250 mL of total
    blend in a tractable time may be a stretch for some feedstocks.
  - Dispense rate is exquisitely sensitive to powder height in the
    trough, humidity, and tribocharging. Closed-loop control on a load
    cell partially absorbs this, but it's a real risk to accuracy.
  - Doesn't eliminate the cross-contamination problem on its own — it
    has to be combined with one of the per-powder-channel architectures
    above.

### 2.6 Pneumatic / aspirated transfer (out of scope per §1a)

A vacuum (or positive-pressure) system aspirates a fixed-volume slug of
powder from a source reservoir and delivers it into the collection cup,
analogously to a pipette. **Sterling has explicitly ruled this out** in
the PR thread on safety and reliability grounds (reactive-metal-powder
hazard plus the risk of overshooting or missing the collection cup); it
is documented here for completeness only.

- **Benefits:**
  - The source reservoirs never have to move; the only moving thing is
    the aspirator tip on a gantry, similar to a liquid-handling robot.
  - Volumetric metering by displacement is very repeatable for free-
    flowing powders.
- **Pitfalls:**
  - The aspirator tip is a *shared* wetted surface. To stay
    cross-contamination-clean it has to be either disposable (same
    autonomy problem as 2.1) or rigorously self-cleaned between
    powders (blow-down, ultrasonic bath, etc.) — neither of which is
    cheap.
  - Filtering vacuum exhaust to keep metal powder out of the pump and
    out of the room is a non-trivial safety problem, especially for
    reactive feedstocks like Ti-6Al-4V.
  - Inert-atmosphere v2 becomes much harder because the system now
    actively moves gas through the powder.

### 2.7 Hybrid: per-powder hopper feeding a shared, self-cleaning auger

A bank of N powder hoppers (no auger of their own) gravity- or
vibratorily-feeds a *single* augered dispense tube. Between powders, a
purge cycle flushes residual powder from the auger into a waste port,
optionally followed by a brush, blow-down, or ultrasonic clean.

- **Benefits:**
  - Splits the difference on BOM: N hoppers + N feed valves + 1 motor +
    1 auger.
  - Reservoirs are simple — just hoppers with a closable bottom — and
    can be larger (deeper) than in 2.3/2.4 for the same footprint.
- **Pitfalls:**
  - The cleaning step is the entire ballgame and we have no evidence yet
    that any cleaning method gets the auger flight clean enough to hit
    the cross-contamination spec on Ti-6Al-4V → IN718 transitions, where
    even sub-percent contamination is a real metallurgical concern.
  - Purge powder is wasted feedstock. For 30 powders × many blends per
    campaign, this can become significant for expensive alloys.
  - Verification of "clean enough" is itself a hard problem and probably
    requires an in-line sensor (e.g. XRF, LIBS) or destructive sampling.

## 3. Cross-cutting concerns (independent of architecture)

These apply to whichever architecture is picked and so don't drive the
top-level choice, but they constrain it.

- **Mass measurement.** A single load cell under the collection cup is
  the simplest closed-loop signal and works for every architecture
  above. Resolution requirement: ±0.1 wt% of 250 mL of, say, IN718
  (≈ 2 kg/L) is ≈ 0.5 g, which is easy. ±0.1 wt% of an individual 1-mL
  trace addition is ≈ 2 mg, which requires a high-resolution cell and
  serious vibration isolation.

  Sterling's PR-thread comment narrows this further with a concrete
  per-build mass envelope. Given the two L-PBF machines targeted
  downstream (Mastrex MX-120 ≈ 220 g/build, Aconity MIDI ≈ 440 g/build,
  both at 3× hopper fill of apparent-density powder) and the upstream
  graphite-crucible volumes for the induction furnace (225 cm³ and
  400 cm³), a single dose campaign is expected to be in the
  **~100–1000 g** range, while occasional rare-earth or trace
  additions will be in the **single-mg-to-gram** range. No single
  A&D balance covers both ends with sub-mg resolution; in the A&D
  family the candidates the team is currently weighing are:

  - **FZ-523** — 520 g capacity, 1 mg resolution: covers a full
    MX-120 / MIDI dose cycle in one shot, but isn't fine enough for
    individual trace additions.
  - **HR-202i** — 220 g / 0.1 mg, with a 51 g / 0.01 mg fine mode:
    enough for an MX-120 build envelope and excellent for trace
    additions, but light on capacity for MIDI.
  - **HR-300i** — 320 g / 0.2 mg: a single-balance compromise that
    *almost* covers the MIDI build envelope.

  The most likely outcome is a **two-station weighing setup** — one
  high-resolution balance (e.g. HR-202i, or the existing HR-100A) for
  trace and small additions on a thin Al-foil "inner inner" crucible,
  plus a higher-capacity balance (e.g. FZ-523 or FZ-2202) for the
  large Al crucible, Al shot, and bulk additions. The architecture
  choice in §2 should therefore not assume a *single* cup / load-cell
  position; whichever option is built needs to either (a) deliver
  cleanly into either of two cups at different weighing stations, or
  (b) be replicated in a small-station and large-station variant.
  This pushes mildly in favor of architectures where the cup can move
  (the cup-on-gantry variant of 2.2, or 2.3/2.4 with two parking
  positions for the head) over those that hardwire one cup beneath
  the dispense field.
- **Electrical grounding of the collection vessel.** Per Sterling's PR
  comment, the aluminum crucible / vial that catches the dispensed
  powder will be **grounded** (copper tape, conductive cup support, or
  similar; possibly even biased) to control electrostatic effects that
  otherwise dominate the behavior of fine metal powders falling into
  a small target. The cup-support fixture must therefore include an
  intentional, low-resistance ground path. Critically, that path must
  be made through a flexible, low-stiffness link (thin wire braid or
  conductive foam) so that it does **not** add a parasitic spring path
  to the load cell and bias the weighing — the same constraint as the
  vibration-isolation bullet, just applied to the electrical bond.
- **Vibration coupling.** The vibration motor from #25 is for promoting
  flow at the auger / hopper interface. It must be mechanically isolated
  from the load cell under the collection cup, or the cell signal will be
  unusable during dispense. This applies equally to all of 2.2, 2.3, and
  2.4 — Will pointed out on an earlier draft that there's no a-priori
  reason 2.3/2.4 can decouple the dispense head from the cup but 2.2
  cannot, so the previous wording singling out 2.2 has been removed. In
  every case the practical fix is the same: rubber/silicone vibration
  isolators between the dispense-side structure and the cup support, and
  blanking out load-cell samples while the vibration motor is energized.
- **Powder safety.** Reactive metal powders (Ti, Al) are a fire and
  inhalation hazard. The architecture must accommodate (a) sealed
  hoppers, (b) a dust-tight enclosure around the dispense path, and (c)
  inerting in v2. Architectures 2.2 and 2.3 enclose most cleanly;
  2.6 is the worst.
- **Refill workflow.** "Minimal human intervention" is a *per-blend*
  goal, not a *per-campaign* goal. The architecture should make
  reservoir refill safe and unambiguous (e.g. swappable cartridges in
  2.3/2.4, lidded hoppers in 2.2). Each reservoir should carry an ID
  (printed barcode, RFID, or just a slot index) so the controller can
  cross-check that "powder X is actually in slot Y" before dispensing.
- **Calibration data.** Whatever architecture wins, every powder × every
  channel needs a flow-rate model. The repository already plans for a
  Python software stack (#25); this is where that model lives. The
  architecture choice mostly affects how many independent models exist
  (N in 2.2, 1 + per-cartridge correction in 2.3/2.4, 1 in 2.7,
  where N is the §1 "loaded subset" of ~8–12 rather than 30).

## 4. Recommendation and next steps

### 4.1 Synthesis of PR-thread feedback (Will + Sterling)

The two main review threads on this draft — Will's per-section
[review][willreview] and Sterling's long architectural [comment][sterlingcomment]
— pull in compatible directions, with a couple of useful tensions. This
subsection pulls them together explicitly so the ranking below is
traceable to the discussion rather than to any single line edit.

[willreview]: https://github.com/vertical-cloud-lab/powder-doser/pull/31#pullrequestreview-4265422312
[sterlingcomment]: https://github.com/vertical-cloud-lab/powder-doser/pull/31#issuecomment-4423553706

**Where they agree (and how that landed in the doc):**

- *Don't size for 30 powders simultaneously.* Will: ~8–10 metals is the
  realistic per-alloy limit, and the per-campaign refill is also the
  swap point for which subset is loaded. Sterling: even before full
  autonomy, back-to-back blends drawn from a larger pool (e.g.
  30-choose-6) are valuable, so the architecture must keep a path to
  growing the addressable element library — not just be capped at the
  loaded subset. → §1 was rewritten to ~8–12 *active* reservoirs with a
  required path to a larger off-line library (e.g. the swappable
  cartridge rack of §2.3 / 1 × N 2.4).
- *Cartridges over hoppers, where reasonable.* Will explicitly likes the
  shared-head + cartridge architectures (§2.3 and the 1 × N variant of
  §2.4); Sterling's preference for cartridge-style reload to support
  larger element libraries points the same way. → §2.3 promoted; 2.4
  pitfall split by sub-variant; 1 × N 2.4 promoted to a serious
  candidate alongside 2.3.
- *Configuration between campaigns must be quick and simple.* Both
  reviewers said this in different words. → reflected in the §3
  reservoir-management bullet and the §4 follow-up issue list, and in
  why 2.3 / 1 × N 2.4 are carried forward despite the clutch unknown.
- *Out-of-scope mechanisms.* Sterling argued air-displacement and
  scraping out, and pneumatic out for safety/targeting; Will's review
  effectively concurred by treating §2.5 (vibratory-only) as
  marginal for varied L-PBF feedstocks. → §1a out-of-scope flags;
  §2.6 reclassified out of scope; §2.5 deprioritized in §4.

**Where they apply pressure in different places:**

- Sterling pushes the *dispense site* to be heavy: every powder gets an
  auger + tap + vibration stack, and ideally an adjustable auger
  angle (§1a). That is mechanically cheapest in §2.2 (each channel
  already owns its own actuators), and most expensive in §2.3 / 2.4
  (where the tap and vibration motor must either travel with the
  shared head or live on each cartridge — adding mass, wiring, or
  per-cartridge BOM). Will's enthusiasm for §2.3 / 1 × N 2.4 implicitly
  bets that a clean shaft-engagement clutch makes the per-cartridge
  cost worth it; if the clutch is hard, the bet flips back toward
  §2.2.
- Sterling pushes the *weighing side* to be heavy: 100–1000 g per build
  with single-mg trace additions, possibly two stations (§3). That
  pulls mildly in favor of architectures whose collection point can be
  moved or replicated (small-station + large-station), which §2.2's
  moving-cup variant and §2.3's cartridge carousel both accommodate
  more naturally than a strictly stationary cup.
- Sterling adds the *electrical-grounding* requirement on the
  collection vessel; Will's review didn't touch this. The constraint
  (flexible, low-stiffness ground link) is architecture-agnostic and
  is captured in §3.

**Net implication for the ranking:** the choice between §2.2 and
§2.3 / 1 × N 2.4 is less about footprint and more about a single
high-leverage prototype — the shaft-engagement clutch. Until that is
de-risked, §2.2 stays the v1 reference (Sterling-favored mechanism
density, easy to build); as soon as the clutch is demonstrated, §2.3
/ 1 × N 2.4 (Will-favored cartridge style, larger addressable element
library) becomes equally attractive. The §4 follow-up issues are
written so both prototypes can proceed in parallel.

### 4.2 Ranking and follow-ups

Folding in the PR-thread feedback shifts the recommendation. With the §1
clarification that only ~8–12 powders need to be loaded at a time
(the rest are swapped at refill), 2.2's footprint pitfall is much
less severe; with §1a's auger + tap + vibrate triplet baked in at every
station, 2.2 and 2.3 are mechanically more similar than the original
draft suggested; and with Will's note that the 1 × N variant of 2.4
collapses to a single motion axis with no dispense-over-cartridges
problem, **the 1 × N linear variant of 2.4 should also be carried as a
serious candidate** alongside 2.3 — the difference between "rotating
carousel of cartridges past a fixed head" and "fixed row of cartridges
with a head sliding past" is small enough that the same shaft-engagement
prototype answers both.

The current ranking is therefore:

- **2.2 (N parallel channels) as the v1 reference design**, sized for
  the §1 loaded subset (~8–12 channels) rather than the full 30, with
  every channel carrying the §1a auger + tap + vibrate triplet. Most
  directly satisfies the cross-contamination requirement and reuses
  the #25 actuator stack verbatim per channel.
- **2.3 (cartridge carousel) and the 1 × N variant of 2.4 as the
  principal single-motor alternatives**, to be prototyped together
  since they share the cartridge + clutch design.
- **2.5 (vibratory-only)**: deprioritized per Will's review; powder-
  dependent throughput and humidity/tribocharging sensitivity make it
  a poor fit for the L-PBF feedstock list. Note that vibration is
  still present at every dispense site as part of the §1a triplet —
  this option is just rejected as the *primary* dispense element.
- **2.6 (pneumatic)**: out of scope per Sterling's PR comment
  (reactive-powder safety, plus targeting risk).
- **2.7 (shared self-cleaning auger)**: blocked on the unknown "is
  the cleaning good enough" question and so should not be the v1
  path.

Concrete follow-ups worth opening as their own issues:

1. A 1-channel mechanical prototype of 2.2 using the exact #25 BOM
   *plus* electrical grounding of the cup per §3, to characterize the
   dispense element in isolation (flow rate vs. step rate, accuracy
   limit, vibration coupling, PSD preservation, electrostatic
   behavior with and without grounding).
2. A 1-cartridge prototype of 2.3 / 1 × N 2.4 focused only on the
   shaft-engagement clutch and on the cartridge as a printable unit,
   since that is the part with the most unknowns.
3. A control-board capacity study: a Pi Zero 2 W + bonnet probably
   can't host 8–12 step/dir pairs directly, let alone 30, so what
   GPIO-expander or smart-stepper bus closes the gap?
4. A cross-contamination measurement protocol — independent of
   architecture — so the candidate designs can be compared
   quantitatively rather than argumentatively.
5. A weighing-station design study against Sterling's per-build mass
   envelope (~100–1000 g typical, with single-mg trace additions),
   sizing one or two A&D balances (FZ-523 / HR-202i / HR-300i /
   existing HR-100A) and deciding whether the doser delivers into a
   single cup or hands off between two stations.

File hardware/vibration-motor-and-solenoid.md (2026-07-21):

# Auger drive, vibration motor, and solenoid — parts identification

Resolves [#24](https://github.com/vertical-cloud-lab/powder-doser/issues/24).
Companion to the Archimedes auger CAD proposed in PR
[#16](https://github.com/vertical-cloud-lab/powder-doser/pull/16) (housing
≈ 20 mm OD × 100 mm tall). Once PR #16 lands, the auger CAD will live at
[`cad/auger/`](https://github.com/vertical-cloud-lab/powder-doser/tree/main/cad/auger).

## Goals (from #24)

* Small enough to mount on / next to the 20 mm OD auger housing.
* A **drive motor** to **rotate the auger** itself (this is what
  actually meters the powder); preferably **direct-coupled to the
  auger shaft**, with belt drive as a fallback.
* A **vibration motor** to free bridged powder, mounted on the
  **stationary auger housing or hopper wall** (not on the rotating
  auger itself — wires can't follow a rotating shaft without a
  slip ring, which we want to avoid). Ideally with **variable
  frequency and amplitude**.
* A **solenoid** mounted **externally** (e.g. as a tap that strikes the
  housing) to dislodge stuck powder.
* All driven from a **Raspberry Pi Zero 2 W** (3.3 V GPIO, limited drive
  current), so a small **driver / breakout board** is needed for each
  actuator.

## Rotating vs stationary parts (no slip ring needed)

To make the wire-routing constraints explicit:

* **Stationary** (mounted to the frame / housing): the Pi Zero 2 W,
  the Perma-Proto Bonnet, all three driver breakouts (DRV2605L,
  DRV8871, DRV8825), the power supply / supplies, the vibration
  motor (epoxied to the housing or hopper wall), the solenoid (on
  a printed bracket beside the housing), and the **stepper motor
  body** (bolted to a bracket co-axial with the auger).
* **Rotating**: only the **auger shaft itself**. The shaft is
  driven by the stepper through a **flexible shaft coupler**
  (item 12) which sits *outside* the powder-side housing.
* **Wires never cross a rotating boundary.** All four motor leads
  on the stepper, the two leads on the vibration motor, and the
  two leads on the solenoid land on stationary boards, so no slip
  ring is needed. The flex coupler is the only mechanical link
  between the rotating and stationary domains.

## TL;DR — recommended bill of materials

> **Vendor design files** (mechanical CAD, PCB sources, drill guides) for the
> parts below are mirrored under [`vendor-files/`](vendor-files/) where the
> upstream license permits, with manual-download links for the rest.

| # | Part | Qty | Approx. price (USD) | Source / link |
|---|---|-----|---|---|
| 1 | Adafruit DRV2605L Haptic Motor Controller breakout (I²C) | 1 | $7.95 | [adafruit.com/product/2305](https://www.adafruit.com/product/2305) |
| 2 | Vibrating Mini Motor Disc — ERM coin, 10 mm × 2.7 mm, 3 V | 1 | $1.95 | [adafruit.com/product/1201](https://www.adafruit.com/product/1201) |
| 3 | Linear Resonant Actuator (LRA) — ~10 mm coin, ~175–235 Hz (optional alternative to #2; Adafruit's old #1631 LRA is **discontinued**, so source a comparable LRA from Precision Microdrives, Vybronics, or Digi-Key if you want to A/B against the ERM) | 0–1 | ~$5 | [precisionmicrodrives.com LRAs](https://www.precisionmicrodrives.com/lra-linear-resonant-actuator-vibration-motors) |
| 4 | JF-0530B 5 V mini push–pull solenoid (~9.6 × 19 × 22 mm, ~4.5 mm stroke) | 1 | $7.50 | [adafruit.com/product/412](https://www.adafruit.com/product/412) |
| 5 | Adafruit DRV8871 DC Motor Driver Breakout — 3.6 A peak, built-in flyback clamps + current limit, screw terminals, takes PWM logic in directly | 1 | $7.50 | [adafruit.com/product/3190](https://www.adafruit.com/product/3190) |
| 6 | Adafruit Perma-Proto Bonnet Mini Kit for Pi — Pi-HAT-shaped solder substrate that the two breakouts and the Pi Zero 2 W's 2×20 header mate to | 1 | $4.95 | [adafruit.com/product/2310](https://www.adafruit.com/product/2310) |
| 7 | 5 V / ≥2 A external supply *(only needed if you do **not** use the consolidated single-supply variant — see "Power supply" below; if you use the buck converter (item 15) you can omit this and item 8)* | 1\* | — | any 5 V barrel-jack PSU |
| 8 | 2.1 mm barrel-jack breakout for the 5 V supply input on the Bonnet *(omit when using the consolidated single-supply variant)* | 1\* | $0.95 | [adafruit.com/product/373](https://www.adafruit.com/product/373) |
| 9 | 0.1" headers, jumper wires, 100 µF / 10 V bulk cap (across the DRV8871 motor supply) | — | — | any |
| 10 | NEMA 11 bipolar stepper motor — 28 mm faceplate, 5 mm shaft, 0.67 A/phase, 10 N·cm holding (StepperOnline 11HS18-0674S) | 1 | $13–15 | [omc-stepperonline.com 11HS18-0674S](https://www.omc-stepperonline.com/nema-11-bipolar-1-8deg-10ncm-14-16oz-in-0-67a-28x28x45mm-4-wires-11hs18-0674s) |
| 11 | **Pololu Tic T500** USB / TTL serial / I²C / analog / RC stepper-motor controller — pre-soldered carrier with on-board MP6500 driver, 4.5–35 V `VIN`, ~1.5 A/phase (≤2.5 A with airflow), high-level "go to position N" commands so the host MCU does **not** generate step pulses; built-in safe-state `~EN` handling sidesteps the boot-time-pull-up gotcha called out by the Edison review | 1 | $32.95 | [pololu.com/product/3135](https://www.pololu.com/product/3135) |
| 11-alt | Pololu DRV8825 stepper-driver carrier — cheaper bare step/dir carrier; on-board current-limit pot, 1/32 microstepping, accepts 3.3 V STEP/DIR/EN logic from the Pi (use this if you want to save ~$17/channel and don't mind generating step pulses on the Pi) | 1 (in place of item 11) | $15.95 | [pololu.com/product/2133](https://www.pololu.com/product/2133) |
| 12 | 5 mm ↔ 5 mm flexible shaft coupler (or 5 mm ↔ auger shaft diameter) for direct-drive to the auger | 1 | $3–6 | any (Amazon / McMaster) |
| 13 | **Mean Well GST60A12-P1J** desktop AC adapter (12 V / 5 A / 60 W, fixed output, 2.1 × 5.5 mm barrel plug, IEC-C14 inlet) — sized to power the stepper *and* (via item 15) the 5 V rail in the consolidated single-supply variant. Order from Digi-Key (Adafruit #352, the original fixed-12 V pick, went out of stock 2026-Q2 with no Adafruit replacement; the only Adafruit-stock 12 V / 5 A option is the **adjustable** #4880, which we deliberately avoid here so the output can't be mis-knobbed). Add a Digi-Key IEC-C14 line cord (item 13a) and a 2.1 mm barrel-jack-to-screw-terminal pigtail (item 13b) to the same cart — both ship separately from the brick. | **1 per system** (not per channel) | $18.60 | [digikey.com Mean Well GST60A12-P1J](https://www.digikey.com/en/products/detail/mean-well-usa-inc/GST60A12-P1J/7703712) |
| 13a | IEC-C14 line cord, US 3-prong NEMA 5-15P → C13, ~6 ft (the GST60A12-P1J ships **without** an AC cord) | **1 per system** | ~$5 | Digi-Key (e.g. Tripp Lite P006-006 or Qualtek 234007-01); any standard "PC power cord" works |
| 13b | 2.1 × 5.5 mm DC barrel jack → screw-terminal pigtail / panel jack (so the brick's barrel plug lands on the bonnet's 12 V screw terminals) | **1 per system** | ~$2.50 | Digi-Key (e.g. CUI Devices PJ-002A + screw-terminal block, or any "DC power jack adapter" on the [Digi-Key barrel-jack page](https://www.digikey.com/en/products/filter/barrel-power-connectors/436)); Adafruit [#368](https://www.adafruit.com/product/368) is the equivalent if you'd rather grab it from the Adafruit cart |
| 14 | 100 µF / 25 V electrolytic across the stepper driver's `VMOT` / `GND` (Pololu specifically calls this out as required for the DRV8825; the Tic T500 also benefits from a local bulk cap on its `VIN`) | 1 | <$0.50 | any |
| 15 | **Pololu D24V22F5** 5 V / 2.5 A step-down (buck) regulator — 12 V → 5 V, lets a single 12 V supply power the Pi *and* the DRV8871 solenoid rail, eliminating the second wall-wart and item 8 | 1 | $18.95 | [pololu.com/product/2858](https://www.pololu.com/product/2858) |
| 16 | **Auger-tilt servo** — Adafruit "Standard Size - High Torque - Metal Gear" digital servo (HD-1810MG, ~3 kg·cm, ±1° repeatability, 5 V PWM input) for the wiper-style angular-positioning add-on described under "Auger drive motor → Auger-tilt / wiper-style angular positioning" below | 0–1 *(optional add-on)* | $22.50 | [adafruit.com/product/1142](https://www.adafruit.com/product/1142) |
| 16-alt | Cheaper micro-servo alternative for the tilt axis — Adafruit Micro Servo (SG-92R, ~2.5 kg·cm, plastic gears, ~3° repeatability — fine for ±15° wipers if the auger assembly is light) | 0–1 *(in place of item 16)* | $5.95 | [adafruit.com/product/169](https://www.adafruit.com/product/169) |
| 17 | M2/M3 servo-horn → auger-tilt-bracket hardware (printed bracket lives in the auger CAD from PR #16; this row covers the screws + the metal servo horn that ships with item 16) | 0–1 *(only with item 16/16-alt)* | <$2 | bench-stock / hardware store |
| 18 | **Pololu 33 V / 9 W shunt regulator** — clamps stepper back-EMF transients on the 12 V `VMOT` rail so a wall-wart-powered system can't push the DRV8825 carrier past its 45 V abs max during deceleration / back-driving (33 V trip point sits comfortably above 12 V nominal so it draws no current normally) | 1 | $14.95 | [pololu.com/product/3776](https://www.pololu.com/product/3776) |
| 19 | **Baseplate-tilt linear actuator** — Glideforce GF01-121010-1-66 (12 V brushed DC lead-screw actuator, **100 mm stroke**, 100:1 gearing, 4.3 kgf / 9.4 lb dynamic load, ~17.6 mm/s no-load, IP66, integrated **limit switches at both ends of stroke** so it safely stops itself at full extend/retract). Pivot-mounts between the chassis frame and the underside of the mounting plate (one end on each) to swing the whole plate from **horizontal (0°) to vertical (90°)** — see "Baseplate-tilt linear actuator" subsection below. Limit-switch variant is preferred over the feedback-pot variant (`-2-66`) because the Pi Zero 2 W has no on-board ADC, and timed-run positioning against the hard end-stops is plenty accurate for a horizontal↔vertical aim that only changes between runs. | **1 per system** *(not per channel)* | $79.95 | [pololu.com/product/4467](https://www.pololu.com/product/4467) |
| 19-alt | Generic 12 V mini linear actuator (~100 mm stroke, ~7–10 lb force, built-in limit switches, two-wire polarity-reversal control) — Amazon search "12V linear actuator 100mm". Lower duty-cycle quality than the Glideforce, plastic gearbox, but plug-compatible with the same DRV8871-driven wiring below. | 1 per system *(in place of item 19)* | ~$25–35 | Amazon / eBay (e.g. ECO-WORTHY, JQDML, Eintosti families) |
| 20 | Second **Adafruit DRV8871 DC Motor Driver Breakout** — drives the linear actuator (item 19/19-alt) off the 12 V rail. Brushed DC + integrated end-stops = textbook DRV8871 load; same part as item 5 (which drives the solenoid), so you can buy two of #3190 and not stock anything extra. Two PWM/DIR-style Pi GPIOs from `pigpio` software-PWM are sufficient (the actuator only moves between runs, so hardware-PWM is not required). | **1 per system** *(only with item 19/19-alt)* | $7.50 | [adafruit.com/product/3190](https://www.adafruit.com/product/3190) |

Total for the full actuator stack (items 1, 2, 4, 5, 6, 10, 11, 12, 14, 18)
with the **default Tic T500** driver: **≈ $98/channel** plus
**≈ $65 system-shared** (Mean Well 12 V brick + IEC cord + barrel pigtail,
D24V22F5 buck, Pi Zero 2 W + heat sink + microSD + Pi USB PSU)
→ **≈ $163** for a single-channel v1.0 build.

Add **item 16 (auger-tilt servo, $22.50)** if you want the optional
wiper-style angular-positioning feature — bringing the v1.0 single-channel
total to **≈ $186** (Tic) or **≈ $169** (DRV8825-alt). The cheaper
micro-servo (item 16-alt, $5.95) drops those numbers to **≈ $169** /
**≈ $152**.

Add **item 19 (Glideforce baseplate-tilt linear actuator, $79.95) + item 20
(second DRV8871, $7.50)** if you want the whole-mounting-plate
horizontal↔vertical tilt — **+$87.45 system-shared** (one set per
system, not per channel), bringing the v1.0 single-channel total to
**≈ $250** (Tic) / **≈ $233** (DRV8825-alt). The generic-Amazon
alternate (item 19-alt, ~$30) drops the linear-actuator adder to ~$37.

Substitute the cheaper bare DRV8825 carrier (item 11-alt, $15.95) for
the Tic T500 (item 11, $32.95) and the per-channel cost drops by
~$17 to **≈ $81/channel** (≈ $146 total for v1.0). The trade-off is
that you generate the step pulses on the Pi yourself instead of
sending high-level "go to position N" commands over USB; see the
"Driver" subsection below.

The **two-PSU fallback** (drop item 15; add items 7 and 8) lands in
the same ballpark (~$148) but uses **two wall plugs** instead of one.

Prices above are pulled directly from each vendor's product page (USD,
single-unit price; Pololu has volume breaks at qty 5/25/100 if you're
batching the N-channel ring from PR #35).

\* Items 7 and 8 are only used in the *dual-supply* variant. If
you use the recommended single-supply variant (12 V wall-wart +
item 15 buck converter), set their quantity to zero.

Everything in this list is a **pre-packaged board with screw terminals
or 0.1" headers** — no transistor / diode / gate-resistor sizing
needed. You solder the two breakouts and the Pi's 2×20 header onto
the Perma-Proto Bonnet, screw the motor and solenoid leads into the
DRV2605L and DRV8871 terminals respectively, and you're done.

## What to order first (grouped by vendor)

> **Operating-mode note (per maintainer feedback).** The system dispenses
> **one powder at a time** into the scale (so we can attribute mass to
> a single channel). This means the **12 V wall-wart only ever has to
> source one stepper's worth of `VMOT` current at a time**, not all
> N channels in parallel — so the Edison review's "12 V/3 A is too
> small for 12 channels holding" concern does **not** apply to the
> normal operating mode, as long as the firmware deasserts `~EN` on the
> idle channels (the DRV8825 / Tic both coast at near-zero `VMOT`
> draw with `~EN` deasserted). Keeping every idle channel coasted is
> the recommended firmware default for the N-channel ring (PR #35);
> only one driver is ever enabled at any moment.

The BOM above is sourced from only **four vendors** for v1.0 of one
single-channel module (PR #35). Order quantities below are
**per channel** — multiply by `N` once the ring-frame replicates the
module (e.g., the §2.2 N=12 layout in `design/brainstorming.md`),
except for the Pi Zero 2 W and the wall-wart, which are **shared
across all channels**. Prices and shipping are USD and approximate as
of 2026-Q2; reconfirm at checkout.

### 1. Adafruit ([adafruit.com](https://www.adafruit.com/)) — single cart, ~$30 + ship per channel (+$22.50 if adding the optional tilt servo) + ~$38 system-shared (Pi + heat sink + microSD + Pi USB PSU; the 12 V brick now ships from Digi-Key, see §5; +$7.50 system-shared for a second DRV8871 if adding the optional baseplate-tilt linear actuator from §2 below)

| BOM # | Part | Qty / channel | Unit price | Product page |
|---|---|---|---|---|
| 1 | DRV2605L Haptic Motor Controller breakout | 1 | $7.95 | [#2305](https://www.adafruit.com/product/2305) |
| 2 | Vibrating Mini Motor Disc (ERM coin) | 1 | $1.95 | [#1201](https://www.adafruit.com/product/1201) |
| 4 | JF-0530B 5 V mini push–pull solenoid (**function:** the tap actuator — driven by item 5 to knock powder loose from the housing wall) | 1 | $7.50 | [#412](https://www.adafruit.com/product/412) |
| 5 | DRV8871 DC Motor Driver Breakout (**function:** H-bridge that drives the **solenoid** coil at item 4 — *not* the stepper) | 1 | $7.50 | [#3190](https://www.adafruit.com/product/3190) |
| 6 | Perma-Proto Bonnet Mini Kit for Pi | 1 | $4.95 | [#2310](https://www.adafruit.com/product/2310) |
| — | Raspberry Pi Zero 2 W (if not already on hand) | **1 per system** | $19.05 | [#5291](https://www.adafruit.com/product/5291) |
| — | Mini aluminum heat sink for Pi Zero 2 W (slim 13×13×3 mm, with thermal adhesive — ships peel-and-stick, fits under the Bonnet) | **1 per system** | $0.95 | [#3084](https://www.adafruit.com/product/3084) |
| — | 16 GB microSD card (Class 10, with adapter — for Raspbian/Pi OS) | **1 per system** | $9.95 | [#2693](https://www.adafruit.com/product/2693) |
| — | 5 V / 2.4 A USB power supply with micro-USB cable (for the Pi) | **1 per system** | $7.50 | [#1995](https://www.adafruit.com/product/1995) |
| 16 | **Auger-tilt servo** (Standard size, High-Torque, Metal Gear, digital — for the optional wiper-style angular-positioning add-on; ~±1° repeatability, 5 V PWM input from a Pi hardware-PWM GPIO) | 0–1 per channel *(optional)* | $22.50 | [#1142](https://www.adafruit.com/product/1142) |
| 16-alt | Cheaper micro-servo alternative (SG-92R, plastic gears, ~±3°) | 0–1 *(in place of #1142)* | $5.95 | [#169](https://www.adafruit.com/product/169) |
| 20 | Second **DRV8871 DC Motor Driver Breakout** (only with item 19/19-alt; drives the baseplate-tilt linear actuator off the 12 V rail — same #3190 as item 5, just bump the quantity in the Adafruit cart from 1 → 2 when you order) | **1 per system** *(optional, only with item 19)* | $7.50 | [#3190](https://www.adafruit.com/product/3190) |

### 2. Pololu ([pololu.com](https://www.pololu.com/)) — single cart, ~$67 + ship per channel (default Tic T500 + shunt regulator), or ~$50 + ship if you swap to the DRV8825 carrier; +$79.95 system-shared if adding the optional baseplate-tilt linear actuator (item 19)

| BOM # | Part | Qty / channel | Unit price | Product page |
|---|---|---|---|---|
| 11 | **Tic T500** USB / serial / I²C stepper-motor controller (**default** — high-level USB control, no Pi-side step-pulse generation, on-board safe-state `~EN`) | 1 | $32.95 | [#3135](https://www.pololu.com/product/3135) |
| 11-alt | DRV8825 stepper-driver carrier (cheaper bare step/dir alternative; saves ~$17/channel if you're OK driving STEP/DIR from the Pi) | 1 (in place of item 11) | $15.95 | [#2133](https://www.pololu.com/product/2133) |
| 15 | D24V22F5 5 V / 2.5 A buck regulator (**function:** steps the system 12 V rail down to 5 V to power the Pi *and* the DRV8871/solenoid in the single-supply variant — eliminates the second wall-wart and item 8) | 1 | $18.95 | [#2858](https://www.pololu.com/product/2858) |
| 18 | **33 V / 9 W shunt regulator** (**function:** clamps stepper back-EMF transients on the 12 V `VMOT` rail so the wall-wart-powered system can't push the DRV8825 carrier past its 45 V abs max during deceleration / back-driving) | 1 | $14.95 | [#3776](https://www.pololu.com/product/3776) |
| 19 | **Glideforce GF01-121010-1-66** baseplate-tilt linear actuator (**function:** swings the whole mounting plate from horizontal to vertical; 12 V brushed DC + lead screw, 100 mm stroke, 100:1, 9.4 lb dynamic load, built-in limit switches at both ends of stroke so it can't over-travel — driven by item 20 below) | **1 per system** *(optional add-on)* | $79.95 | [#4467](https://www.pololu.com/product/4467) |

### 3. StepperOnline — ~$15 per channel

| BOM # | Part | Qty / channel | Unit price | Source |
|---|---|---|---|---|
| 10 | NEMA 11 bipolar stepper, 28 mm faceplate, 5 mm shaft, 0.67 A/phase, 10 N·cm holding (StepperOnline 11HS18-0674S) | 1 | ~$13–15 | [omc-stepperonline.com 11HS18-0674S](https://www.omc-stepperonline.com/nema-11-bipolar-1-8deg-10ncm-14-16oz-in-0-67a-28x28x45mm-4-wires-11hs18-0674s) |

> The previously-listed [SparkFun ROB-10848](https://www.sparkfun.com/products/10848)
> turned out to be a NEMA **17** part rated only 0.35 A / 22.5 N·cm
> — both wrong frame size and noticeably under-rated for the auger
> torque budget — so it has been dropped. Use the StepperOnline
> NEMA 11 above. Reconfirm price at checkout.

### 4. StepperOnline / Amazon / McMaster (commodity hardware) — ~$2–5 per channel

| BOM # | Part | Qty / channel | Unit price | Notes |
|---|---|---|---|---|
| 12 | 5 mm ↔ 5 mm aluminum flexible shaft coupler, 18×25 mm (StepperOnline ST-FC01) | 1 | $1.09 | Order from StepperOnline alongside item 10 to consolidate shipping: [omc-stepperonline.com ST-FC01](https://www.omc-stepperonline.com/5mm-5mm-flexible-shaft-coupling-18x25mm-cnc-stepper-motor-shaft-coupler-st-fc01). If the auger from PR #16 ends up using a non-5 mm shaft, swap the bore on the auger side to match (StepperOnline stocks every common bore combo on the same product family). |
| 14 | 100 µF / 25 V electrolytic cap | 1 | <$0.50 | Required by Pololu across DRV8825 `VMOT`/`GND`; also recommended on the Tic T500's `VIN`. |
| 9 | 100 µF / 10 V cap, 0.1" pin headers, jumper wires | as needed | bench-stock | You almost certainly have these. |

### 5. Digi-Key ([digikey.com](https://www.digikey.com/)) — single cart, ~$26 system-shared (12 V brick + line cord + barrel-jack pigtail)

The 12 V system brick lives here instead of the Adafruit cart now that
[Adafruit #352](https://www.adafruit.com/product/352) (the original
fixed-output 12 V / 5 A pick) is out of stock at Adafruit and Digi-Key
with no near-term restock. The Adafruit-stock replacement is the
**adjustable** [#4880](https://www.adafruit.com/product/4880), which
we deliberately avoid — a knob-set output is one accidental nudge away
from feeding 9 V or 12 V into a circuit that wanted exactly 12 V.
[Pololu #1468](https://www.pololu.com/product/1468) is a fixed-12 V
drop-in but lists at **US $40.33**, more than 2× the Mean Well unit
below. So the recommended path is a Mean Well desktop brick from
Digi-Key plus the line cord and barrel pigtail it ships without.

| BOM # | Part | Qty / system | Unit price | Source |
|---|---|---|---|---|
| 13 | **Mean Well GST60A12-P1J** desktop AC adapter — 12 V / 5 A / 60 W, fixed output, 2.1 × 5.5 mm center-positive barrel plug, IEC-C14 inlet | 1 | $18.60 | [digikey.com Mean Well GST60A12-P1J](https://www.digikey.com/en/products/detail/mean-well-usa-inc/GST60A12-P1J/7703712) |
| 13a | IEC-C14 line cord (US 3-prong NEMA 5-15P → C13, ~6 ft) — the GST60A12-P1J ships **without** an AC cord | 1 | ~$5 | Digi-Key (e.g. Tripp Lite P006-006 or Qualtek 234007-01); any standard "PC power cord" works. Skip if you have a spare desktop / monitor cord on hand. |
| 13b | 2.1 × 5.5 mm DC barrel jack → screw-terminal pigtail (so the brick's barrel plug lands on the bonnet's 12 V screw terminals) | 1 | ~$2.50 | Digi-Key [barrel-jack adapters](https://www.digikey.com/en/products/filter/barrel-power-connectors/436) (e.g. CUI Devices PJ-002A in a screw-terminal block); Adafruit [#368](https://www.adafruit.com/product/368) is the equivalent if you'd rather grab it from the Adafruit cart |

### Items to **skip** for the single-supply variant

Items **7** (5 V PSU) and **8** ([Adafruit #373](https://www.adafruit.com/product/373) barrel-jack breakout) are only used in the dual-supply fallback. Don't order them unless you specifically need the two-PSU layout.

### PSC / on-hand check before ordering

The published BYU PSC inventory was spot-checked against the parts above
([psc.byu.edu/available%20for%20purchase](https://psc.byu.edu/available%20for%20purchase),
plus the ECE ELC inventory at [capstone.byu.edu/computing-resources](https://capstone.byu.edu/computing-resources)
and the ECE shop info at [eceshop.byu.edu/information-and-resources](https://eceshop.byu.edu/information-and-resources)).
What's likely already on-campus and worth checking before ordering:

* **Raspberry Pi Zero 2 W** — ECE ELC (416 CB) stocks Raspberry Pis for purchase; confirm the Zero 2 W variant with current ELC staff (contact info on [capstone.byu.edu/computing-resources](https://capstone.byu.edu/computing-resources)) before checkout.
* **Generic stepper-motor driver** — the BYU PSC inventory lists a "Stepper Motor Driver" at ~$10. Brand/model is **not** specified, so confirm whether they stock a Pololu Tic T500 (item 11) or just a bare DRV8825/A4988-class step-and-direction carrier (item 11-alt) before counting on it.
* **Consumables**: 100 µF caps (items 9, 14), 0.1" headers, jumper wires, microSD card, USB power supply, micro-USB cable, and the Pi heat sink (#3084) are the kinds of items the prototyping lab typically stocks for ~free; check before adding to the cart.
* **Wall-wart (item 13)** ships from Digi-Key (Mean Well GST60A12-P1J), and the **DRV2605L / ERM disc / JF-0530B / DRV8871 / Bonnet** actuator-side parts (items 1, 2, 4, 5, 6) are **not** on the published PSC list and should come from Adafruit directly.
* **Tic T500 specifically**: not in the published PSC inventory — order from Pololu unless staff confirms otherwise.

### Suggested first-buy: one channel (v1.0 of PR #35)

For the v1.0 single-channel prototype, **place all five carts above
once with `qty = 1` per item** (default Tic T500 driver) — total
**≈ $163 + shipping** for the electronics, including the Pi Zero 2 W,
the Mean Well 12 V brick (with line cord + barrel pigtail from
Digi-Key), the Pi heat sink, the microSD card, and the
Pi USB power supply. Substitute the DRV8825 carrier (item 11-alt) for
the Tic T500 to bring it down to **≈ $146**.

Add the **optional auger-tilt servo (item 16, $22.50)** if you want
the wiper-style angular-positioning feature — bringing the total to
**≈ $186** (Tic) / **≈ $169** (DRV8825-alt), or **≈ $169** /
**≈ $152** with the cheaper micro-servo (item 16-alt, $5.95).

Add the **baseplate-tilt linear actuator (item 19, $79.95) + a second
DRV8871 (item 20, $7.50)** if you want the
horizontal-to-vertical whole-plate tilt described in the
"Baseplate-tilt linear actuator" subsection below — **+$87.45
system-shared** (one set per system, not per channel). Bringing the
v1.0 single-channel total to **≈ $250** (Tic) / **≈ $233**
(DRV8825-alt). The generic-Amazon alternate (item 19-alt, ~$30)
drops the linear-actuator adder to ~$37 instead.

Multiply
Adafruit/Pololu/StepperOnline line items (but **not** the
wall-wart, the buck, the Pi, the heat sink, the microSD, or the
Pi PSU) by `N` once you're ready to fan out to the N-channel
ring.

## Power supply

The actuators want two distinct rails:

* **12 V / ≥1 A** for the stepper, into the Tic T500's `VIN` (or
  the DRV8825 carrier's `VMOT` if you went with item 11-alt).
* **5 V / ≥1.5 A** for the solenoid coil (peak ~1.1 A inrush)
  *and* the Pi Zero 2 W (~0.7 A under WiFi load), with a common
  ground tied to the stepper supply's GND.

There are two wiring options; **the single-supply variant is
recommended** because it eliminates one wall-wart and one
barrel-jack breakout:

### Recommended: single 12 V supply + on-board buck (item 13 + item 15)

* Use a single **fixed-output 12 V / 5 A barrel-jack brick** (item 13).
  Default: **Mean Well GST60A12-P1J** from Digi-Key
  ([digikey.com Mean Well GST60A12-P1J](https://www.digikey.com/en/products/detail/mean-well-usa-inc/GST60A12-P1J/7703712),
  $18.60), plus an IEC-C14 line cord (item 13a, ~$5) and a 2.1 mm
  barrel-jack-to-screw-terminal pigtail (item 13b, ~$2.50) from the
  same Digi-Key cart — both ship separately from the brick.
  This replaces the previously-recommended fixed-output Adafruit #352,
  which went out of stock at Adafruit and Digi-Key 2026-Q2.
  Adafruit's only in-stock 12 V / 5 A option is the **adjustable**
  [#4880](https://www.adafruit.com/product/4880); we deliberately
  avoid it because a knob-set output can be mis-set to 9 V or 12 V
  by accident. [Pololu #1468](https://www.pololu.com/product/1468)
  is a fixed-12 V drop-in but lists at US $40.33, more than 2× the
  Mean Well unit. Either way the supply only carries ~1 A continuous
  in our worst case so it stays cool.
* Solder a **Pololu D24V22F5** 12 V → 5 V / 2.5 A step-down
  (item 15, [Pololu #2858](https://www.pololu.com/product/2858))
  onto the bonnet next to the DRV8825. It's a pre-built carrier
  with `VIN`, `GND`, and `VOUT` pads on a 0.1" pitch — no
  inductor or feedback-divider sizing needed.
* Wire `VIN/GND` of the buck to the same 12 V net that feeds the
  DRV8825's `VMOT`. Wire `VOUT` to the DRV8871's `VM` and to the
  Pi Zero 2 W's 5 V rail (header pin 2 or 4) on the bonnet. All
  GNDs are already common via the bonnet's ground rail.
* Item 7 (separate 5 V PSU) and item 8 (second barrel-jack
  breakout) become unnecessary — the wall-plug count drops from
  **two to one**.
* Why the D24V22F5 specifically: it's the cheapest Pololu buck
  carrier that comfortably handles the Pi's startup transient
  plus the JF-0530B's ~1.1 A inrush in the same 5 V rail (2.5 A
  continuous, ~3 A peak). The D24V10F5 (1 A continuous) is too
  small once the solenoid is firing while the Pi is busy on WiFi.
* **Pololu shunt regulator across the 12 V rail to clamp stepper
  back-EMF (item 18 — required, not optional).** When the stepper
  decelerates (or is back-driven by powder binding in the auger),
  it dumps energy back into `VMOT`. With a wall-wart supply
  (which can't sink current), that energy bumps the 12 V rail
  upward as a transient spike — enough, in worst cases, to push
  past the DRV8825 carrier's 45 V absolute max. A
  [Pololu shunt regulator](https://www.pololu.com/category/249/shunt-regulators)
  wired in parallel with the 12 V rail clamps these spikes by
  shunting the excess to a built-in power resistor. For our
  12 V system the **33 V / 9 W variant
  ([Pololu #3776](https://www.pololu.com/product/3776), $14.95)**
  is the right choice — well above the 12 V operating point so it
  draws no current normally, and well under the 45 V `VMOT`
  abs max so it activates before the driver is at risk. Add it to
  the Pololu cart by default; bench-tested couplings without an
  axial load might not strictly need it, but the cost is small
  enough that the safety margin is worth carrying on every build.

### Alternative: two separate wall-warts (items 7, 8, 13)

Keep this option if you already have a 5 V supply on the bench
and don't want to buy a buck converter. In that case wire the
5 V PSU through item 8 to the DRV8871's `VM` (and to a Pi USB
power input), and the 12 V PSU through a screw-terminal pad to
the DRV8825's `VMOT`. Tie all grounds together at the bonnet.
This is also the configuration drawn in the KiCad schematic
([`kicad/`](kicad/)).

## Auger drive motor

### Recommended: NEMA 11 bipolar stepper, direct-coupled to the auger shaft (items 10, 11, 12)

Powder dosing is fundamentally an **angle-counting** problem — one
revolution of the auger displaces a known volume of powder, so a
**stepper** (open-loop position control by counting steps) is the
natural fit. A NEMA 11 bipolar stepper is the smallest standard
frame size and lines up well with the 20 mm OD housing footprint:

* **28 mm × 28 mm faceplate**, ~30–45 mm body length, 5 mm output
  shaft.
* ~0.67 A/phase, ~12 N·cm holding torque — comfortably above what
  a small Archimedes auger metering loose powder needs.
* 200 full steps/rev (1.8°), down to 6400 microsteps/rev with the
  DRV8825 at 1/32 microstepping → sub-degree dose resolution.
* Direct-drive — the auger shaft from `cad/auger/` is sized for a
  5 mm coupler bore, so the stepper output shaft mates to it
  through a **flexible shaft coupler** (item 12). No belt, no
  pulleys, no alignment tooling.

### Driver: Pololu Tic T500 (item 11, **default** — USB / serial / I²C)

Per maintainer feedback, the **[Pololu Tic T500](https://www.pololu.com/product/3135)**
($32.95) is the **default recommended driver** for the auger
stepper. The Tic accepts high-level commands (target position /
target velocity) over USB, TTL serial, I²C, analog voltage
(potentiometer), quadrature encoder, or hobby RC, and generates the
step/dir waveform itself — so a Pi Zero 2 W or Pico W just sends
"go to position N" over USB and the Tic handles acceleration,
deceleration, microstepping, and current limiting. It also has an
**on-board safe-state `~EN`** behaviour, which sidesteps the
boot-time pull-up issue called out by the Edison review for the bare
DRV8825.

Spec highlights:

* **`VIN`: 4.5 V – 35 V** — comfortably handles our 12 V rail.
* **~1.5 A/phase** continuous without a heat sink (≤2.5 A with
  airflow) — well above the 0.67 A/phase that the NEMA 11
  (item 10) needs.
* On-board MP6500 driver, current limit set in software (no `Vref`
  pot to dial in by hand).
* Configured once via the free [Pololu Tic Control Center
  GUI](https://www.pololu.com/docs/0J71/3) over USB; the same USB
  cable then becomes the runtime control link to the host.
* Safe-state `~ENABLE` on power-up — no risk of the coils
  energizing while the host MCU's GPIOs are still hi-Z during boot.

Wire-up:

* `VIN` / `GND` ← **12 V external PSU** (item 13), with the
  100 µF / 25 V cap (item 14) right at those pins.
* Stepper coils → the Tic's `A1, A2, B1, B2` screw terminals (or
  pre-soldered headers, depending on the variant you order).
* Host link → either a USB cable from the Pi Zero 2 W's micro-USB
  OTG port, or `SCL`/`SDA` for I²C, or `TX`/`RX` for TTL serial.
  No `STEP` / `DIR` pulses on the host — the Tic generates them
  internally from high-level position/velocity commands.
* Common GND between the 12 V PSU, the Tic's logic GND, and the Pi.

The Tic is a **standalone board with its own USB / screw-terminal
IO**, so unlike the DRV8825 carrier it doesn't sit on the
Perma-Proto Bonnet. It mounts to the chassis next to the bonnet,
sharing the 12 V rail and a common ground with everything else.

The schematic in `hardware/kicad/` still draws the bare DRV8825
carrier (item 11-alt) because it's the cheaper baseline and easier
to capture as a single-page placeholder symbol; the net labels
(`STEP`, `DIR`, `~EN`, `VMOT`) are unused when the Tic is the
driver, since the Tic talks to the host over USB / I²C / serial
instead.

### Driver alternative: Pololu DRV8825 stepper-driver carrier (item 11-alt)

The bare **DRV8825 carrier** ($15.95) is the cheaper, lower-level
alternative — pick this if you'd rather save ~$17/channel and don't
mind generating the step pulses on the Pi yourself. It's also the
driver drawn in the KiCad schematic.

It provides:

* Two integrated H-bridges with built-in flyback handling (no
  external diodes).
* On-board **current-limit potentiometer** — set once with a
  multimeter (or by reading `Vref`) to ~0.67 A/phase to match the
  motor; no current-sense resistor sizing needed.
* 1/1, 1/2, 1/4, 1/8, 1/16, 1/32 microstepping selected by three
  mode pins (tie to 3.3 V or GND through the Bonnet).
* 3.3 V-tolerant `STEP` / `DIR` / `~ENABLE` logic inputs that the
  Pi's GPIOs drive directly.
* Screw-terminal-friendly 0.1" pin rows for both the motor coils
  (`A1/A2/B1/B2`) and motor supply (`VMOT/GND`).

Wire-up:

* `VMOT` / `GND` ← **12 V external PSU** (item 13), with the
  100 µF / 25 V cap (item 14) right at those pins. *Do not* power
  the DRV8825 from the 5 V rail or the solenoid PSU — the stepper
  needs the higher voltage to commutate quickly.
* `A1, A2` ← stepper coil A; `B1, B2` ← stepper coil B (check
  motor datasheet for pairs).
* `STEP` ← Pi **GPIO20**, `DIR` ← Pi **GPIO21**, `~ENABLE` ← Pi
  **GPIO16** (active-low; pull high to coast the motor between
  doses to save power and heat). Add a **10 kΩ pull-up from
  `~ENABLE` to `+3V3`** so the driver coasts safely while the Pi's
  GPIOs are hi-Z during boot (per Edison review).
* `RESET` and `SLEEP` tied together and pulled high (otherwise the
  driver stays asleep).
* Common GND between the 12 V PSU, the DRV8825 logic GND, and the
  Pi.

### Auger-tilt / wiper-style angular positioning (optional add-on)

> **Two tilt axes, two different parts.** This subsection covers the
> **per-channel wiper sweep** of a *single auger* through a small arc
> (typically ±30–±90°) — a fast, low-torque motion used during a
> dispense to aim across multiple targets on the scale. For tilting the
> **entire mounting plate** from fully horizontal to fully vertical
> as a per-system aim *between* dispense runs, see the
> "Baseplate-tilt linear actuator" subsection below instead.

A second motion axis — **tilting** the whole auger assembly through
a repeatable arc, windshield-wiper style — lets one channel
deposit at multiple target positions on the scale (e.g. sweeping
across a row of crucibles, or aiming the dispense nozzle at a
specific spot in a well). Because dosing is **angle-counted on the
auger spin axis** (Tic T500 + NEMA 11, above), the tilt axis only
needs **absolute, repeatable position control over a limited arc**
(typically ±30°-±90°). That's almost exactly what a **hobby servo**
does, and it's much cheaper / smaller than a second stepper for
this duty cycle.

**Recommended — digital metal-gear servo (item 16, default).**
The [Adafruit Standard High-Torque Metal-Gear digital servo
(HD-1810MG, #1142, $22.50)](https://www.adafruit.com/product/1142)
hits the right point in the trade-space:

* **Digital control loop + metal gears** → ~±1° repeatability
  across the full ~180° travel (analog plastic-gear servos drift
  2–3° between commanded positions, which we can see at the
  scale).
* **5 V logic-level PWM input** — drive directly from a Pi GPIO
  (the Pi has hardware PWM on GPIO12 / GPIO18; either is fine,
  and GPIO13/19 are spares) using the stock `pigpio` or
  `gpiozero.AngularServo` libraries. No extra driver IC needed.
* **5 V power** — shares the same buck-derived 5 V rail as the
  Pi and the DRV8871. Steady-state draw is ~5–15 mA at idle and
  150–250 mA while slewing; peak stall is ~600–800 mA but a
  wiper sweep never stalls. The Pololu D24V22F5 buck (item 15,
  2.5 A continuous / 3 A peak) has plenty of headroom alongside
  the Pi (~0.7 A) and a brief solenoid tap (~1.1 A peak), since
  the tilt and the tap don't fire simultaneously.
* ~3 kg·cm holding torque with metal output spline — comfortably
  above the auger-assembly tilt load (a NEMA 11 + 5 mm coupler +
  short auger weighs <100 g; the moment arm from the tilt pivot
  is short).

**Cheaper alternative — micro servo (item 16-alt).** If the auger
assembly is light enough and the required arc is <30°, the
[Adafruit Micro Servo (SG-92R, #169, $5.95)](https://www.adafruit.com/product/169)
will work, at the cost of plastic gears and ~3° repeatability.
Same PWM-from-Pi wiring; same 5 V rail.

**Mechanical mount.** Print a single-axis pivot bracket sized for
the standard 40.4×19.8 mm "standard size" servo body (item 16) or
the 23×12.2 mm micro-servo body (item 16-alt). The bracket lives
with the auger housing CAD (PR #16); two M2 screws fix the servo
horn to a 3D-printed cradle that carries the stepper + auger
sub-assembly, and the servo body bolts to the chassis. Item 17
covers those screws + the metal servo horn that ships in the
#1142 accessory bag.

**Why not a second NEMA 11 + Tic T500 on the tilt axis?**
Doable, and reuses the same driver topology as the auger spin —
but it adds ~$48/channel (motor + Tic), needs a limit switch for
homing (steppers are open-loop position from power-on), and
brings the per-channel cost back above the "<$200" envelope.
The single-axis tilt arc never needs sub-degree precision (it's
positioning a dispense aim, not metering mass), so the servo
hits the goal with far less hardware.

**Software stub (Pi-side, `gpiozero`).** Using GPIO12 (hardware
PWM channel 0) for the tilt servo:

```python
from gpiozero import AngularServo
from time import sleep

tilt = AngularServo(
    12,
    min_angle=-45,
    max_angle=+45,
    min_pulse_width=0.5e-3,   # 500 µs
    max_pulse_width=2.5e-3,   # 2500 µs
)

# Sweep three repeatable wiper positions for a 3-target dispense:
for angle in (-30, 0, +30):
    tilt.angle = angle
    sleep(0.4)            # let the servo settle (~150°/s typical)
    # ... drive the auger Tic to dose mass at this position ...
```

Calibrate the per-target angles **once** by jogging the servo
under software control while watching the dispense point on the
scale, then store the calibrated angles in the channel's config
file. Because the servo is absolute-position (PWM duty → angle),
no homing routine is needed at power-on — it goes straight to the
first commanded angle.
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

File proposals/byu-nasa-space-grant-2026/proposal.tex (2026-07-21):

%%%%%%%%%%%%%%%%%%%%%%%%%%%%%%%%%%%%%%%%%%%%%%%%%%%%%%%%%%%%%%%%%%%%%%%%%%%%%%
% BYU / Utah NASA Space Grant Consortium Fellowship -- Proposal Narrative
% Applicant:       Sam Charles (undergraduate, Brigham Young University)
% Faculty advisor: Sterling Baird (BYU Vertical Cloud Lab)
% Cycle:           2026 (deadline: 8 May 2026)
% Length target:   up to 5 pages, per program guidelines (3-5 page cap).
%                  Layout intentionally relaxed for readability rather than
%                  compressed -- per applicant feedback the proposal reads
%                  better when given room to breathe.
%
% Build (MiKTeX or TeX Live):
%   cd proposals/byu-nasa-space-grant-2026
%   latexmk -pdf proposal.tex
%
% Required LaTeX packages (auto-installed by MiKTeX with [MPM]AutoInstall=1) --
% keep this list in sync with the \usepackage lines below:
%   geometry, times, microtype, graphicx, caption, titlesec, fancyhdr,
%   lastpage, enumitem, multicol, natbib, hyperref
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

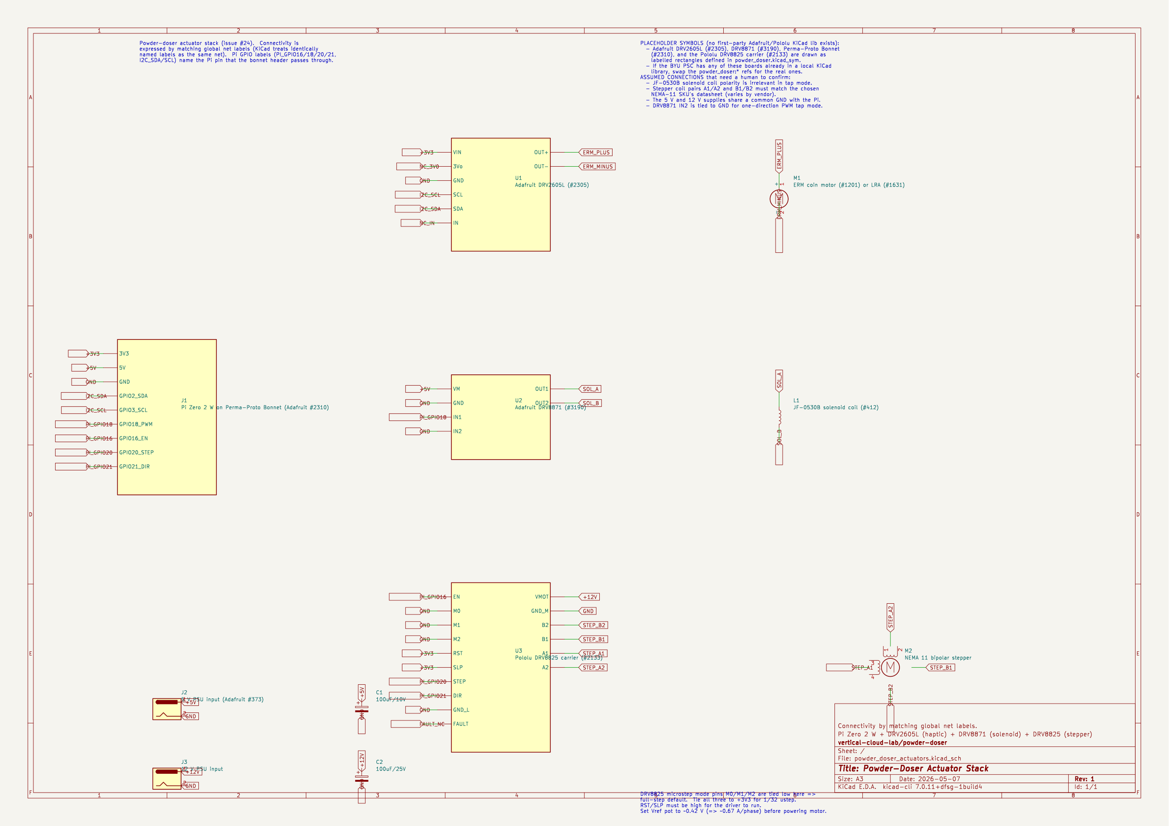
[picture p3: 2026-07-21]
hardware/kicad/powder_doser_actuators.png

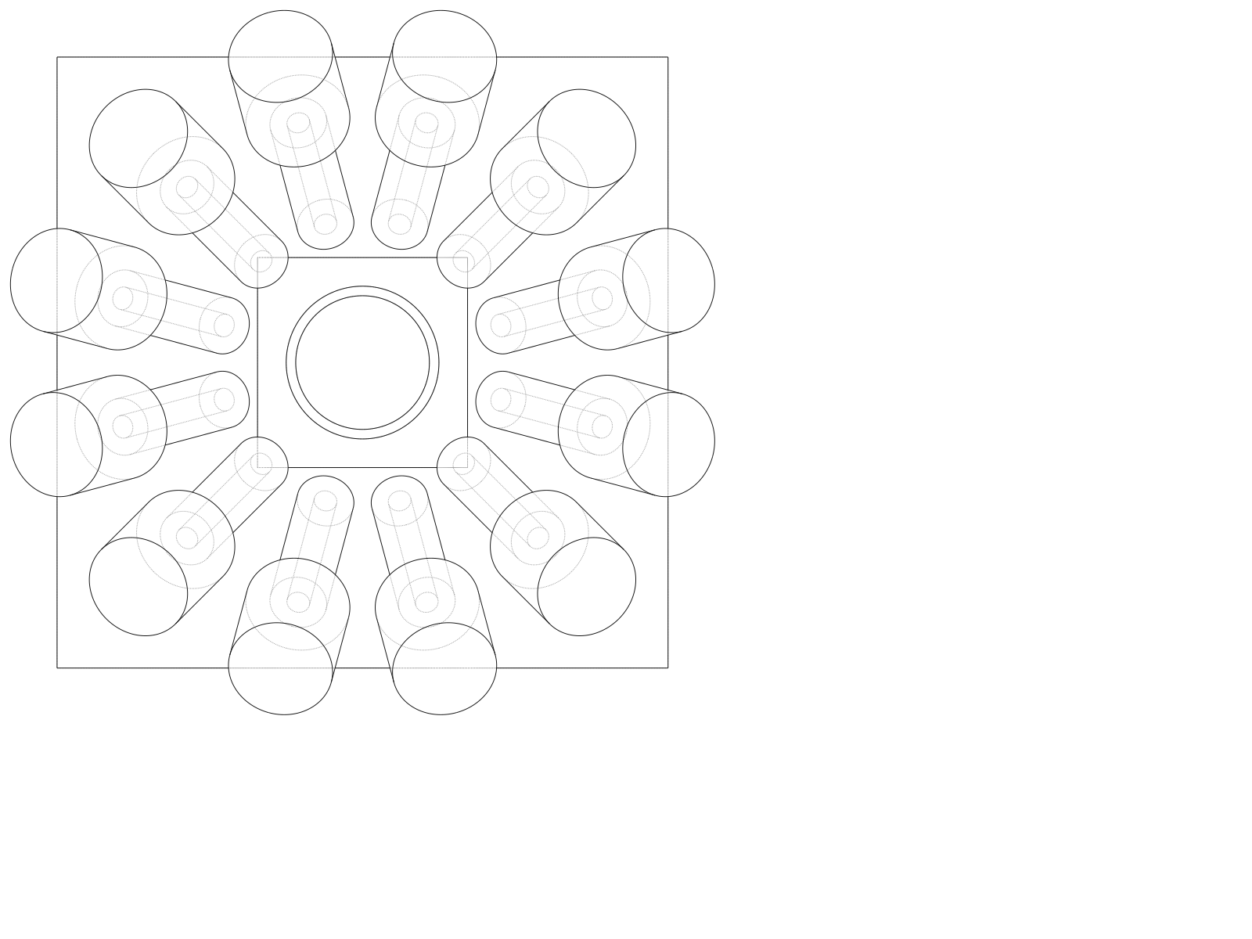
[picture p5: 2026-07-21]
design/cad/inward-collection-cup/inward_collection_cup_top.png

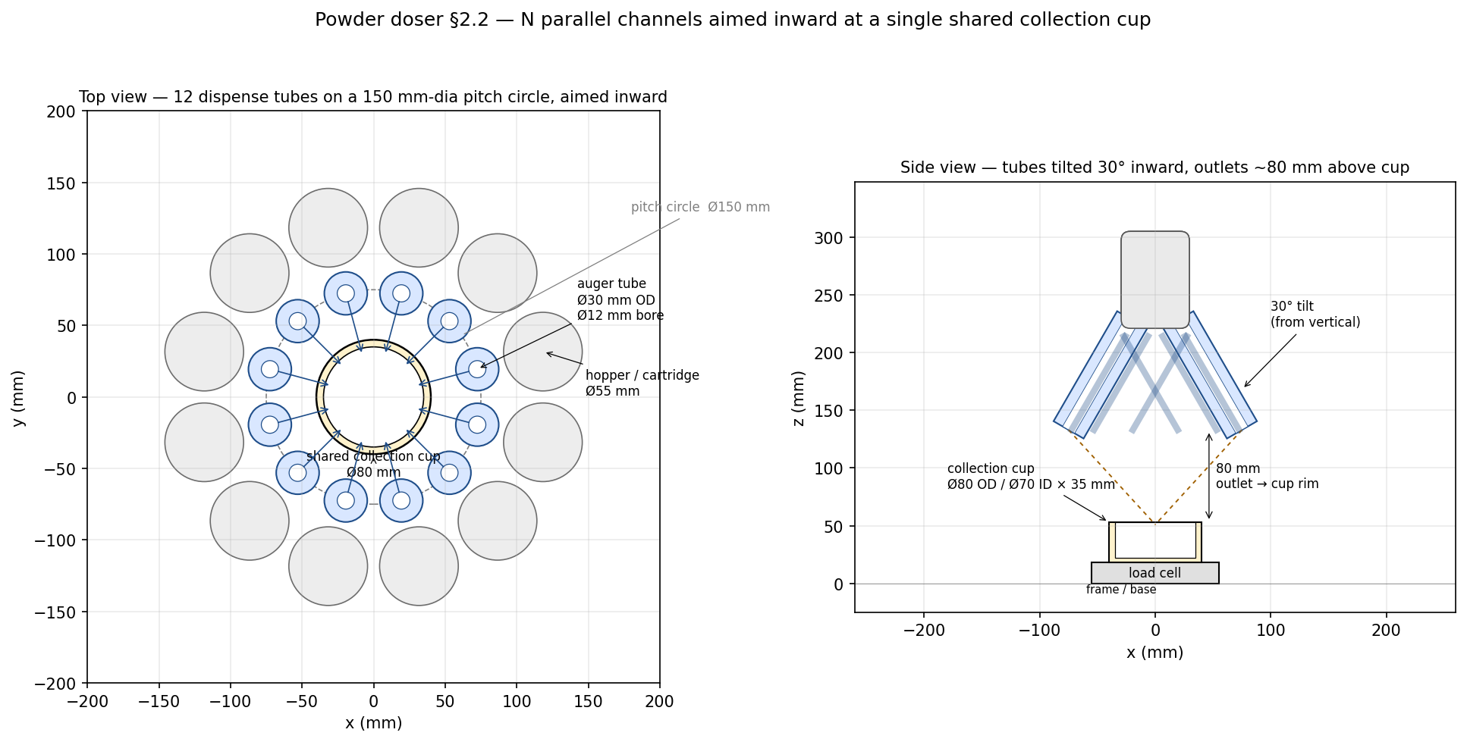
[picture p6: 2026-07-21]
design/cad/inward-collection-cup/sketch_top_side.png

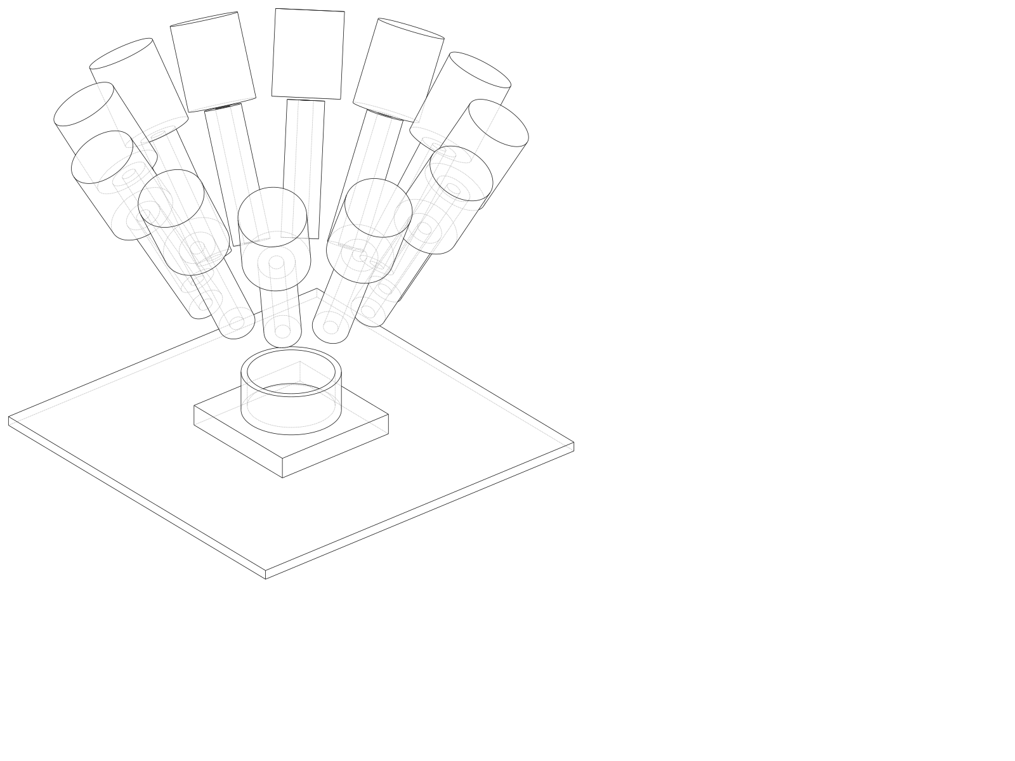
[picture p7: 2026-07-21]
design/cad/inward-collection-cup/inward_collection_cup_iso.png

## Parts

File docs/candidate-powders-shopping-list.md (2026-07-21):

# Shopping list — food-safe surrogate powders

Per the request on
[`#19`](https://github.com/vertical-cloud-lab/powder-doser/pull/19#issuecomment-4444335961),
this is a buy-list for the six food-/lab-safe surrogate powders
originally proposed earlier in that PR thread (kept in
[`candidate-powders.md`](candidate-powders.md) under
"Earlier surrogate-powder set"). They are *not* the project's
primary feedstocks — the metal targets are still Si / AlSi10Mg /
the digital-alloy-lab palette — but the surrogates remain useful
for cheap, ambient-air bring-up of the doser hardware while we wait
on inert-atmosphere capability and the custom Al crucibles.

## Quick summary

| # | Powder | Pack size | Indicative unit price (USD) | Vendor (primary) |
|---|---|---|---|---|
| 1 | White (glutinous) rice flour | 24 oz | ~$5–8 | Bob's Red Mill (Amazon) |
| 2 | Brown rice flour | 24 oz | ~$5–8 | Bob's Red Mill (Amazon) |
| 3 | Sodium alginate (food grade) | 50 g | ~$10–12 | Modernist Pantry |
| 4 | Calcium lactate (food grade) | 8 oz | ~$12–13 | Cape Crystal Brands |
| 5 | Carboxymethyl cellulose (CMC) | 8 oz | ~$11–12 | Cape Crystal Brands |
| 6 | Xanthan gum | 8 oz | ~$12–14 | Bob's Red Mill (Amazon / Walmart / Target) |

Indicative single-pack subtotal: **~$55–67 USD** before tax/shipping.
Prices were spot-checked on 2026-05-12 and *will* drift; treat the
links as the source of truth, not the numbers.

A seventh "even-mass mix of all six" entry from the original list
does not need to be ordered — it is made by combining equal masses
of items 1–6 in the lab.

## Validated product links

### 1. White (glutinous) rice flour — Bob's Red Mill, 24 oz

- Standard (gluten-free) line: <https://www.amazon.com/Bobs-Red-Mill-Gluten-White/dp/B07V1YMGLY>
- Organic line (substitute if standard is out of stock):
  <https://www.amazon.com/Bobs-Red-Mill-Organic-White/dp/B07YQL5DDW>
- Typical Amazon price: ~$5–8 per 24 oz bag (fluctuates).

Rationale: baseline "easy-flow", near-spherical-ish starch granule
powder. One bag is plenty for early bring-up.

### 2. Brown rice flour — Bob's Red Mill, 24 oz

- Standard: <https://www.amazon.com/Bobs-Red-Mill-Brown-Flour/dp/B000KEJQ1A/>
- Organic (substitute): <https://www.amazon.com/Bobs-Red-Mill-Organic-Brown/dp/B0013J0GUY/>
- Typical Amazon price: ~$5–8 per 24 oz bag.

Rationale: similar size band to the white rice flour but with bran
fragments — introduces shape/size heterogeneity.

### 3. Sodium alginate — Modernist Pantry, 50 g (food-grade, E401)

- Vendor product page:
  <https://modernistpantry.com/products/sodium-alginate.html>
- Typical Modernist Pantry price: ~$11.99 / 50 g jar; 400 g
  "Kitchen Alchemy" size also listed on the same page if a larger
  order is preferred.
- Amazon alternative (different brand, larger pack):
  Pure Sodium Alginate, Molecular Gastronomy / Non-GMO,
  <https://www.amazon.com/Alginate-Molecular-Gastronomy-Non-GMO-Certified/dp/B013GARWFQ>

Rationale: fine, slightly hygroscopic biopolymer — moderate-cohesion
data point. 50 g is more than enough for surrogate testing; only
order the larger size if we plan to repeat-fill the hopper many
times.

### 4. Calcium lactate — Cape Crystal Brands, 8 oz (food grade)

- Vendor product page:
  <https://www.capecrystalbrands.com/products/calcium-lactate>
- Typical price: ~$12.95 / 8 oz pouch.
- Amazon alternative (different brand):
  Pure Calcium Lactate (Molecular Gastronomy),
  <https://www.amazon.com/Calcium-Lactate-Molecular-Gastronomy-Certified/dp/B00FT3CT66>

Rationale: crystalline / more angular particles — a useful contrast
to the rounded starch granules.

### 5. Carboxymethyl cellulose (CMC / "cellulose gum") — Cape Crystal Brands, 8 oz

- Vendor product page:
  <https://www.capecrystalbrands.com/products/carboxymethyl-cellulose-cmc-powder>
- Typical price: ~$11.95 / 8 oz pouch.
- Vendor offers 2 oz / 8 oz / 16 oz pack sizes; 8 oz is the
  recommended starting quantity.

Rationale: fibrous, strongly hygroscopic cellulose derivative —
highly cohesive, poor-flow regime endpoint. Will pick up moisture
fast in ambient air; store sealed with desiccant.

### 6. Xanthan gum — Bob's Red Mill, 8 oz

- Amazon: <https://www.amazon.com/Bobs-Red-Mill-Gluten-Xanthan/dp/B078T45FYD>
- Walmart: typically ~$13.98 / 8 oz pouch.
- Target: typically ~$13.39 / 8 oz pouch.

Rationale: very fine, very cohesive biopolymer — the
extreme-cohesion endpoint of the original surrogate set.

## Notes for ordering

- All six are food-grade and shippable to a normal lab address; no
  hazardous-materials handling is required.
- Quantities above are *one* of the smallest sensible retail pack
  size per powder. That is enough for repeated bench tests and the
  even-mass mix; do not bulk-order until we have evidence the doser
  geometry is stable.
- All six are hygroscopic to varying degrees (CMC and xanthan
  worst). On arrival, decant working portions into sealed jars with
  an indicating-desiccant sachet, and keep the original retail
  packaging double-bagged with desiccant in the same desiccator
  workflow described in
  [`candidate-powders.md`](candidate-powders.md#handling-and-storage).
- @swcharles — if the items / pack sizes look right, please go
  ahead and place the order; otherwise flag substitutions here
  before purchasing.

## Disclaimer on prices and links

Prices and stock state at retailers like Amazon, Walmart, and
Target change frequently. The numbers above were spot-checked on
**2026-05-12** and are intended only as ballpark figures for
budgeting. Always re-verify the live price on the linked product
page before placing the order, and substitute an equivalent
food-grade SKU from a different vendor if the linked one is out of
stock.

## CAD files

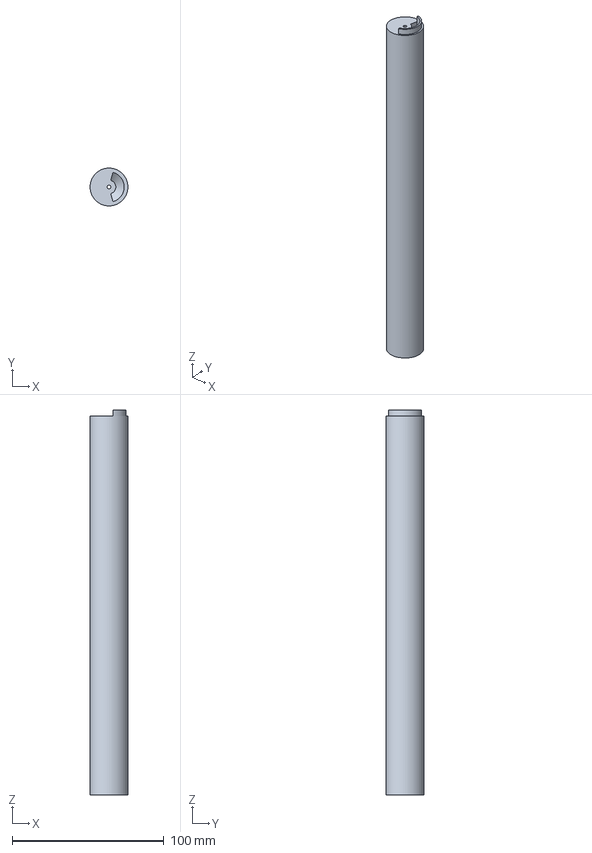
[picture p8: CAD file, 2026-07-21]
cad/auger/archimedes-auger.3mf
25.0 x 25.0 x 254.0 mm

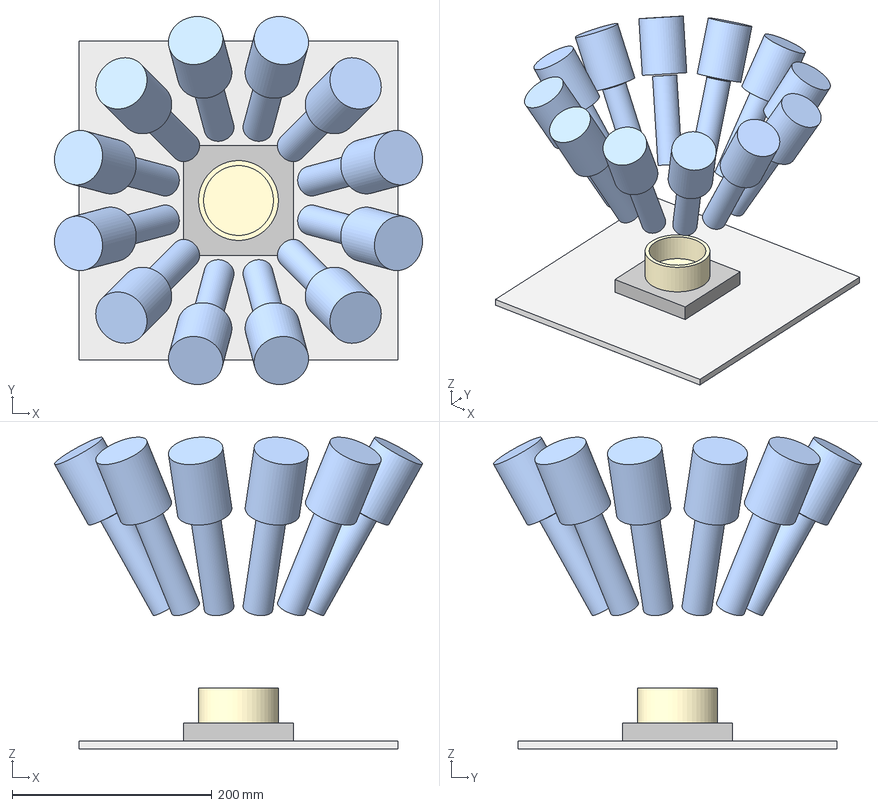
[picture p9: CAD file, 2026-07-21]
design/cad/inward-collection-cup/inward_collection_cup.step
368.8 x 368.8 x 312.3 mm
base
load_cell
cup
channels

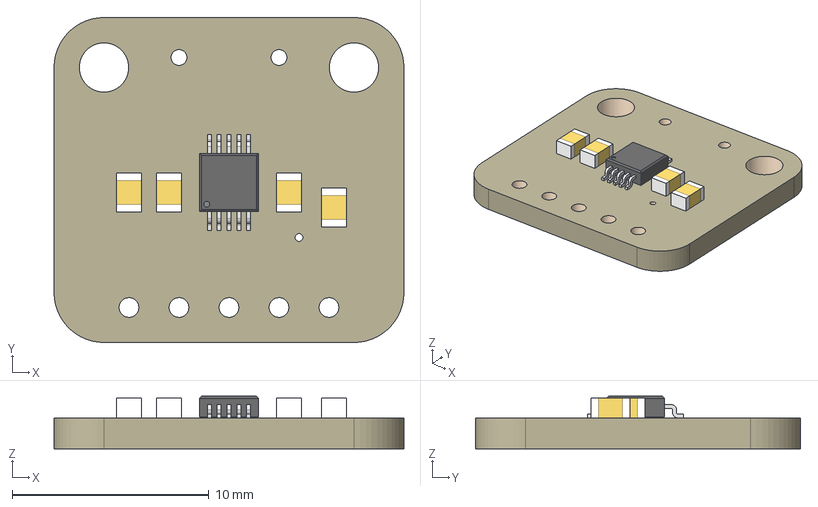
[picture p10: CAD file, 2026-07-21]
hardware/vendor-files/adafruit-2305-drv2605l/cad/2305 DRV2605L.step
17.8 x 16.5 x 2.67 mm
Board
DRV2605LDGS
1uF x 4

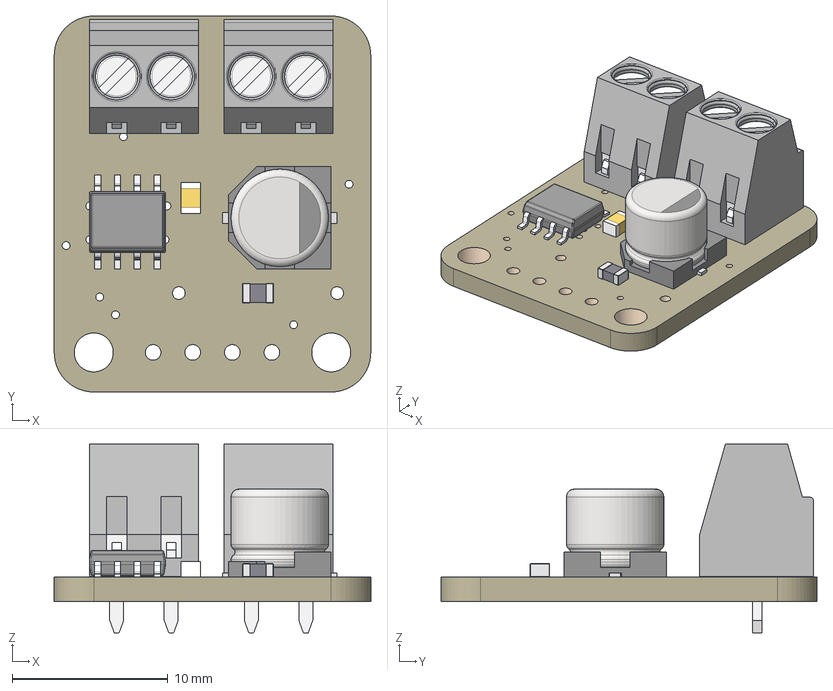
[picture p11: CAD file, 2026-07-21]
hardware/vendor-files/adafruit-3190-drv8871/cad/3190 DRV8871 Breakout.step
20.3 x 24.1 x 12.1 mm
Board
DRV8871
0.1uF/50V
22uF/63V
30K
POWER x 2

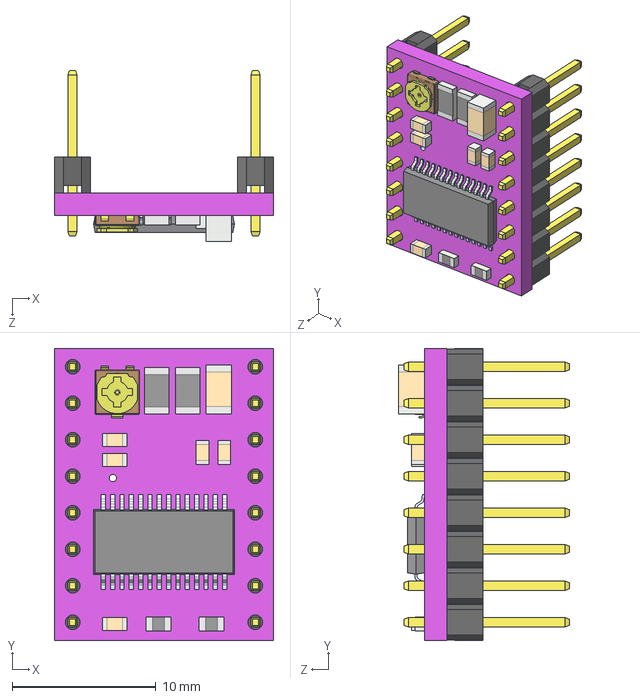
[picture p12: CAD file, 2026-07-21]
hardware/vendor-files/pololu-2133-drv8825/cad/drv8825-stepper-motor-driver-carrier-high-current.step
15.2 x 20.3 x 11.9 mm

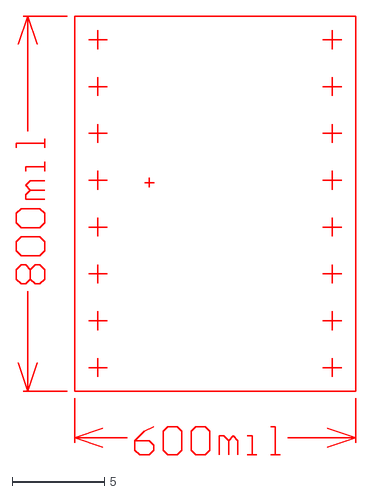
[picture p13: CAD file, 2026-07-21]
hardware/vendor-files/pololu-2133-drv8825/dimensions/stepper-motor-driver-carrier-md20b-drill.dxf
18.4 x 23.8

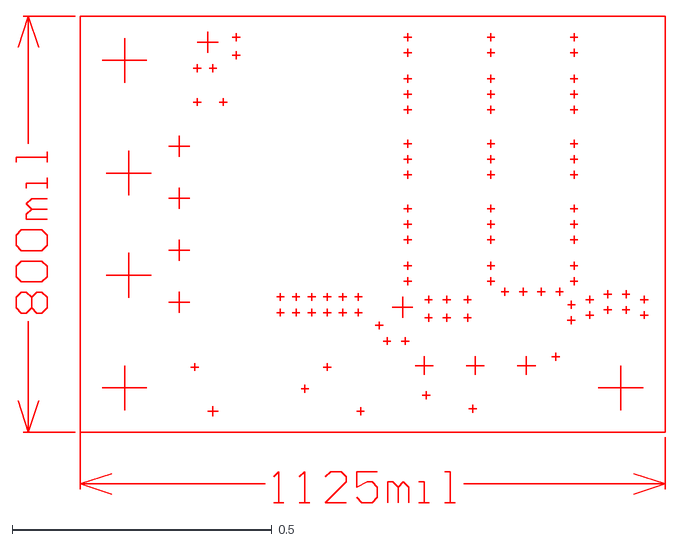
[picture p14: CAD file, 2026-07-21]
hardware/vendor-files/pololu-3776-shunt-regulator-9w/dimensions/tvs01a-drill.dxf
1.25 x 0.936

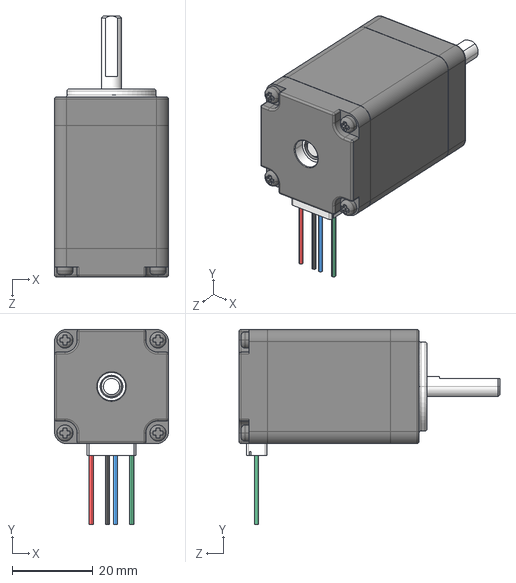
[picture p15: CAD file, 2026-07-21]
hardware/vendor-files/stepperonline-11hs18-0674s/cad/11HS18-0674S.STEP
28.2 x 48.2 x 64.5 mm

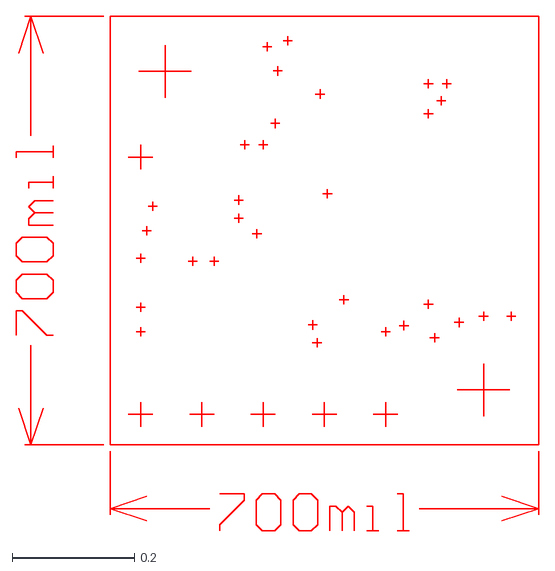
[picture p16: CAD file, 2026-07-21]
hardware/vendor-files/pololu-2858-d24v22f5/dimensions/reg19a-drill.dxf
0.853 x 0.84

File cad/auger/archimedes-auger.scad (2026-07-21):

// ================================================================
// Powder Excavator — Archimedes Auger Attachment  v5 (hollow tube)
// ================================================================
//
// Rotating dispenser tube — hollow cylinder with conical exit funnel,
// top loading slots, and M3 spindle mount. NO internal helix and NO
// central shaft. Powder is metered by rotation + gravity through the
// on-axis exit hole, with de-bridging from the planned solenoid (#25)
// and coin vibration motor (#31).
//
// Architecture history (so future maintainers don't re-litigate this):
//   v1/v2/v2.1  monolithic union() rotor — outer tube + helical fin.
//   v3/v3.1     experiment: split into fixed shaft + rotating housing
//               around a 0.5 mm radial-clearance journal fit.
//   v4          Reverted to monolithic per PR review.
//   v4.1        Added a central support shaft for the helix to print
//               on (real-auger geometry).
//   v5 (here)   Drop the inner core entirely. The H2D test print on
//               2026-05-13 produced a clean outer tube + funnel + cap
//               but the helix / central shaft inside came out as
//               strings. Per PR #16 review thread: "We were able to
//               print this without the inner core, leave the inner
//               core out, and it's fine to make that 'empty core
//               space' larger to reduce the cantilever effect. I don't
//               want powder getting trapped." So:
//                 - helical_fin() and central_shaft() removed from the
//                   union; the assembly is now just tube_walls() +
//                   bottom_funnel() + top_cap().
//                 - The bottom funnel is lengthened (bottom_cap_h
//                   8 mm → 12 mm) so the cone half-angle from vertical
//                   drops below 45° (atan(8.5/12) ≈ 35°) — self-
//                   supporting under any slicer, no helix-inner-edge
//                   bridge to worry about.
//                 - Inner bore (inner_r ≈ 10.5 mm, ID 21 mm) is left
//                   untouched: it's already wide and smooth, with no
//                   inward features for powder to lodge against, so
//                   nothing can get trapped between auger and tube
//                   (there is no auger).
//                 - Throughput is now governed by the exit-hole
//                   diameter + rotation speed + vibration tap, the
//                   autotrickler-style metering scheme. Capacity ≈
//                   80 cm³ usable.
//
// v4 changes vs v2.1 (capacity scale-up — review thread "we need larger
// capacity here"):
//   - total_height   100 mm → 250 mm  (~10")
//   - outer_diameter  20 mm →  25 mm  (slightly larger bore)
//   - The 250 × 25 mm pillar prints vertically inside the Bambu Lab H2D
//     envelope (350 × 320 × 325 mm); ~75 mm Z headroom remaining.
//   - Usable channel volume ≈ 4.5× v2.1 (~63 cm³ vs ~14 cm³).
//   - Everything else (M3 spindle mount, 2 mm wall, 10 mm pitch, 2 mm
//     fin, 4 sectoral top loading slots, conical funnel + 3 mm CAD exit
//     hole, 0.4 mm fin-into-wall sink + 0.2 mm helix z-overlap that
//     keeps the union() CGAL-manifold) is preserved from v2.1.
//
// Hopper: deliberately NOT modelled. Cohesive powders (xanthan gum,
// flour, etc.) tend to bridge and rathole at a hopper-to-tube
// transition, so this design feeds the auger directly through the four
// top-cap loading slots. The companion solenoid (#25, percussive tap)
// and coin vibration motor (#31, continuous low-amplitude shake) are
// the de-bridging strategy; they will mount to the rotor frame in
// follow-up PRs.
//
// Print:   PLA or PETG, 0.2 mm layers, 0.4 mm nozzle, 1.75 mm filament.
//          Vertical orientation (exit hole DOWN on the build plate).
//          3+ perimeters, 40 % gyroid infill, 4 mm brim (small annular
//          bed contact around the exit hole), supports at 50° (helix
//          inner-edge bridge above the funnel + top-cap annulus bridge).
//          After printing, tap the M3 spindle hole with an M3 hand tap.
// Render:  Paste into https://openscad.org/demo/ → F6 (Render)
// Export:  File → Export → Export as STL
// Headless STL + STEP + slices + checks (CI/local):
//   bash cad/auger/render_print.sh
//
// ================================================================

/* [Main Dimensions] */
outer_diameter  = 25;    // mm — outer cylinder OD (v2.1: 20)
total_height    = 250;   // mm — total length (v2.1: 100)
wall_thickness  = 2;     // mm — outer tube wall

/* [M3 Mount — Top] */
// Boss protrudes below the top cap to give 12 mm of M3 engagement.
// After printing, use an M3 hand tap to cut threads.
// M3 minor diameter = 2.459 mm; pilot at 2.5 mm is correct for tapping.
m3_pilot_d      = 2.5;   // mm — M3 pilot hole (tap after print)
top_cap_height  = 6;     // mm — solid cap at top
m3_boss_r       = 4;     // mm — radius of central boss below cap
m3_boss_h       = 6;     // mm — boss height below cap
// Total M3 engagement = top_cap_height + m3_boss_h = 12 mm

/* [Powder Exit — Bottom] */
// Conical funnel guides powder from outer wall to exit hole.
// 3.0 mm CAD diameter accounts for FDM shrinkage; as-printed on a
// 0.4 mm nozzle ≈ 2.5 mm functional diameter. Open with a 2.5 mm drill
// bit if it comes out tight.
exit_hole_d     = 3.0;   // mm — exit hole diameter (CAD)
bottom_cap_h    = 12;    // mm — height of conical funnel section.
                          // v5: 8 → 12 mm so the cone half-angle from
                          // vertical = atan((inner_r - exit_r)/h) ≈ 35°,
                          // well under any slicer's 50° overhang
                          // threshold — funnel is fully self-supporting
                          // without supports or a brim ring.

/* [Loading Opening — Top Cap] */
// Single large pie-slice opening through the top cap (v6, per review
// comment #4464237145: "make it so there's just one opening to put the
// powder into from the top, and that it's larger so it's easier to
// pour into… Even just creating a single larger opening will help").
// Replaces v5's four 7×4 mm sectoral slots, which together gave only
// ~112 mm² of pour area split across four narrow windows. The new
// kidney-shaped opening spans `loading_arc_deg` of the annulus between
// the M3 boss and the inner tube wall — ~250 mm² of clear pour area in
// a single mouth, big enough for a powder scoop or a squeeze-bottle
// nozzle to fit straight in. NOT a hopper — see header note on
// bridging/ratholing for cohesive powders.
loading_arc_deg = 150;   // degrees of the cap annulus opened up
loading_inner_r = 4.5;   // mm — clears m3_boss_r=4 by 0.5 mm
loading_outer_r = 10.0;  // mm — clears inner_r=10.5 by 0.5 mm

/* [Pour Lip — One-sided "slide" / scoop wall] */
// Thin arc wall standing above the top cap on the OUTER rim of the
// loading opening, acting as a one-sided funnel: pour powder against
// the wall and it slides down into the opening rather than skating off
// the flat cap. Non-invasive (3 perimeters thick, ~25% of the cap arc),
// prints in-place with the rest of the part — no separate piece, no
// supports. Set lip_height = 0 to disable entirely.
lip_height      = 4;     // mm — wall height above cap (0 = disabled)
lip_thickness   = 1.2;   // mm — wall thickness (3 perimeters at 0.4 mm)

// ================================================================
// Derived — do not edit
// ================================================================
inner_d         = outer_diameter - 2 * wall_thickness;
inner_r         = inner_d / 2;
outer_r         = outer_diameter / 2;
m3_pilot_depth  = top_cap_height + m3_boss_h;

$fn = 64;

// ================================================================
// Modules
// ================================================================

// Outer tube walls — hollow cylinder, full height.
module tube_walls() {
    difference() {
        cylinder(r=outer_r, h=total_height);
        translate([0, 0, -0.1])
            cylinder(r=inner_r, h=total_height + 0.2);
    }
}

// Conical funnel bottom — directs powder to exit hole as rotation slows.
// Inner surface tapers from (inner_r - 0.5) at the top to exit_hole_d/2
// at the base. Outer surface is a flat cylinder matching the tube OD.
module bottom_funnel() {
    difference() {
        cylinder(r=outer_r, h=bottom_cap_h);
        translate([0, 0, -0.1])
            cylinder(
                r1 = exit_hole_d / 2,
                r2 = inner_r - 0.5,
                h  = bottom_cap_h + 0.2
            );
    }
}
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

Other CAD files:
hardware/vendor-files/pololu-2858-d24v22f5/dimensions/d24v22f5-drill-guide.dxf
hardware/vendor-files/pololu-3776-shunt-regulator-9w/dimensions/shunt-regulator-9w-drill-guide.dxf
cad/auger/archimedes-auger.stl
hardware/vendor-files/adafruit-2305-drv2605l/cad/2305 DRV2605L.f3d
hardware/vendor-files/adafruit-2305-drv2605l/cad/2305 DRV2605L.stl
hardware/vendor-files/adafruit-3190-drv8871/cad/3190 DRV8871 Breakout.f3d

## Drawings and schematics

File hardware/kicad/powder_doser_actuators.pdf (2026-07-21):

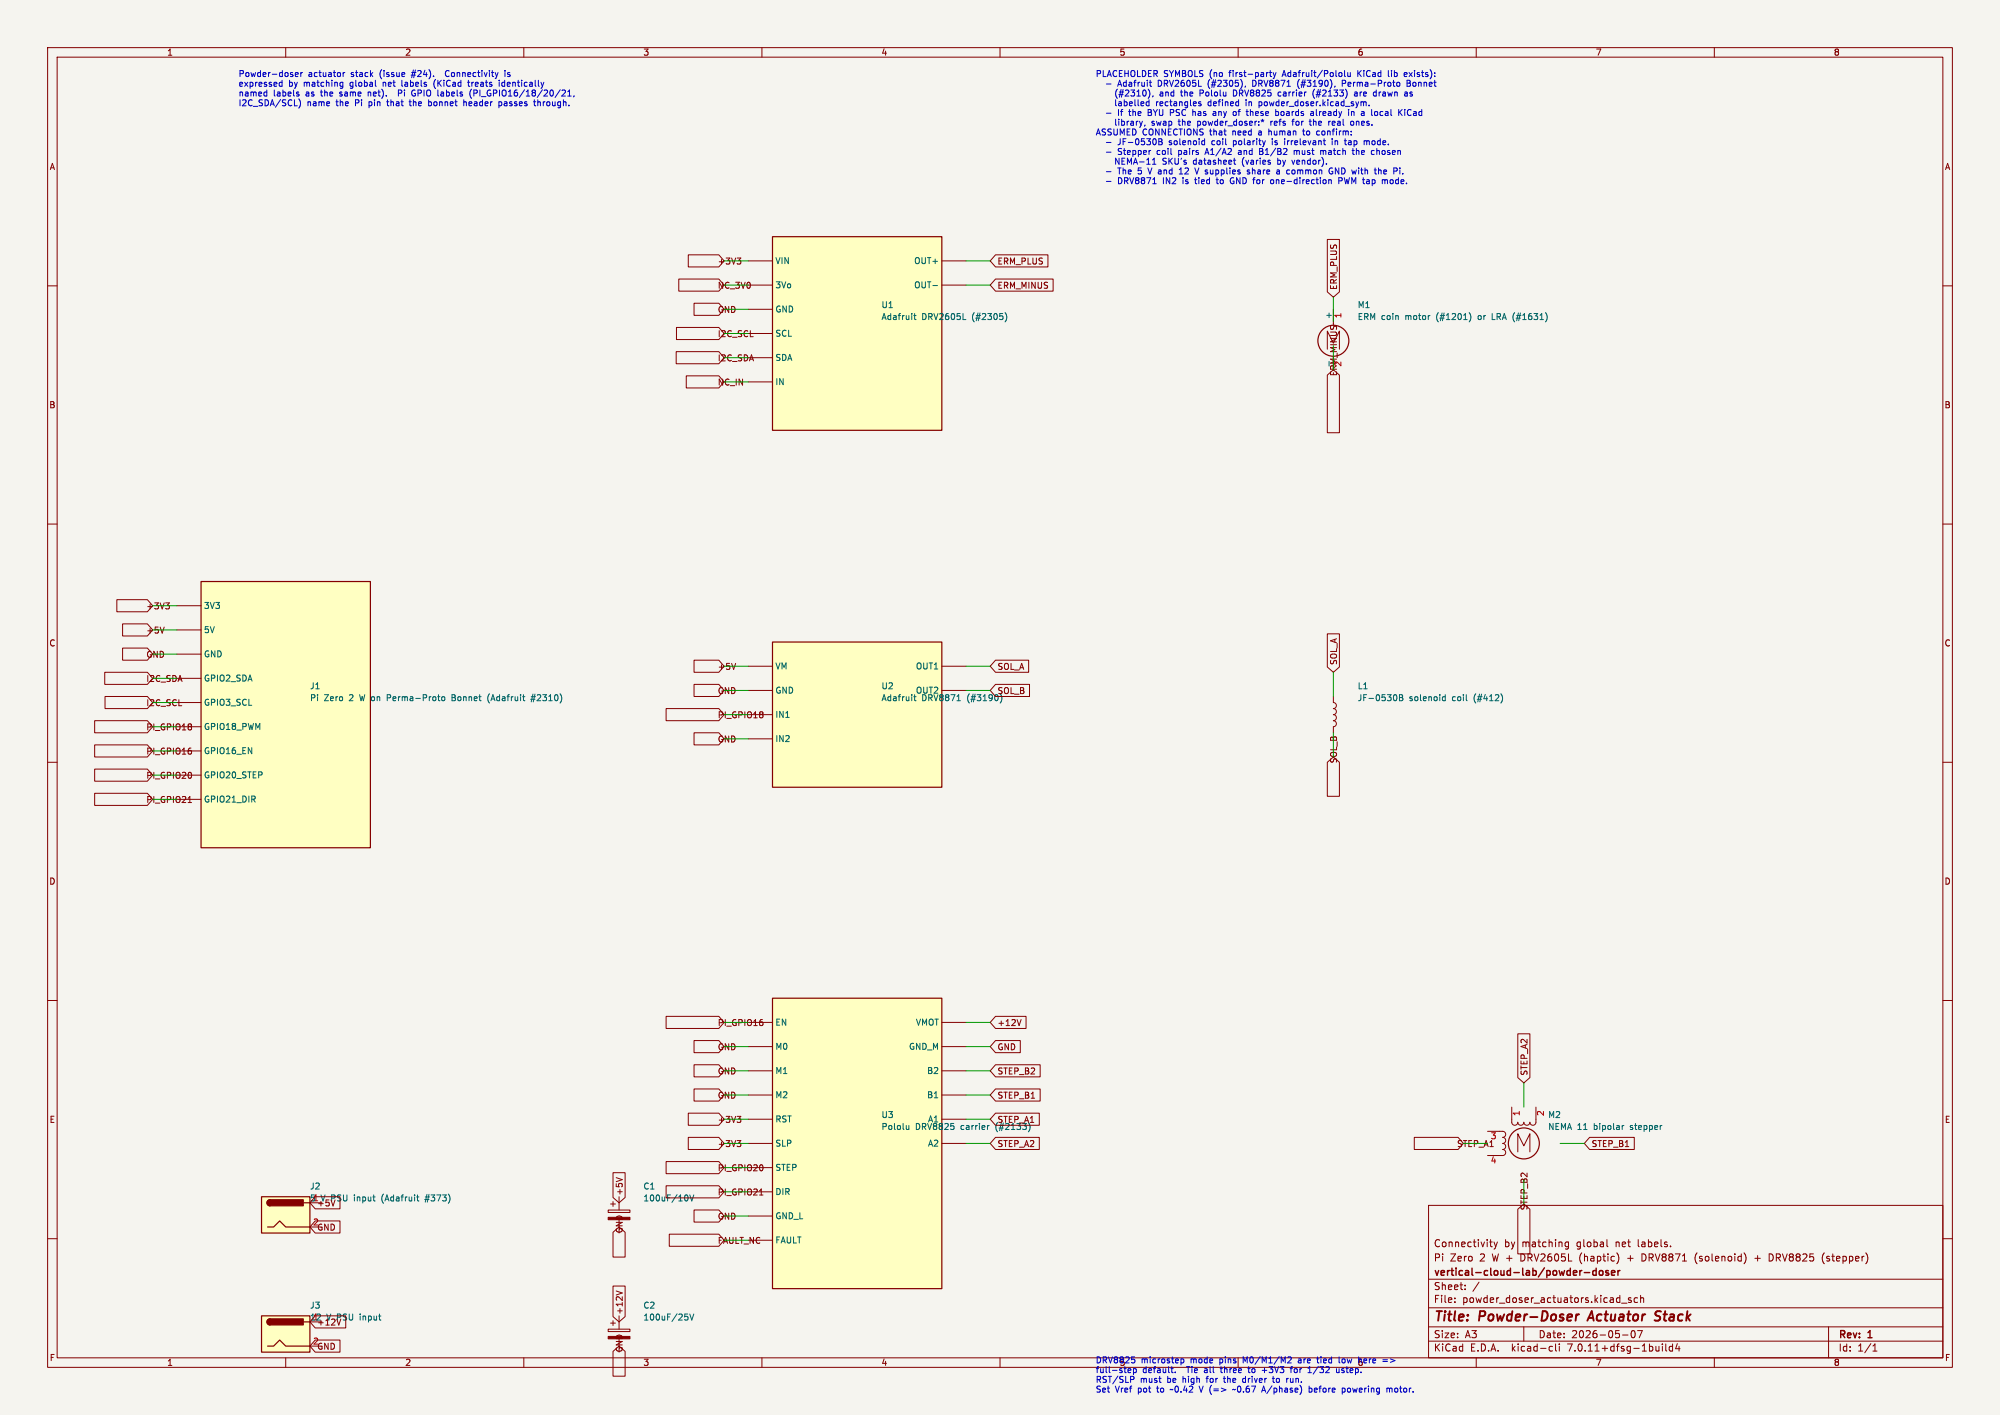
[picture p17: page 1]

-2 M1 ERM coin motor (#1201) or LRA (#1631) 3V3 GPIO18_PWM

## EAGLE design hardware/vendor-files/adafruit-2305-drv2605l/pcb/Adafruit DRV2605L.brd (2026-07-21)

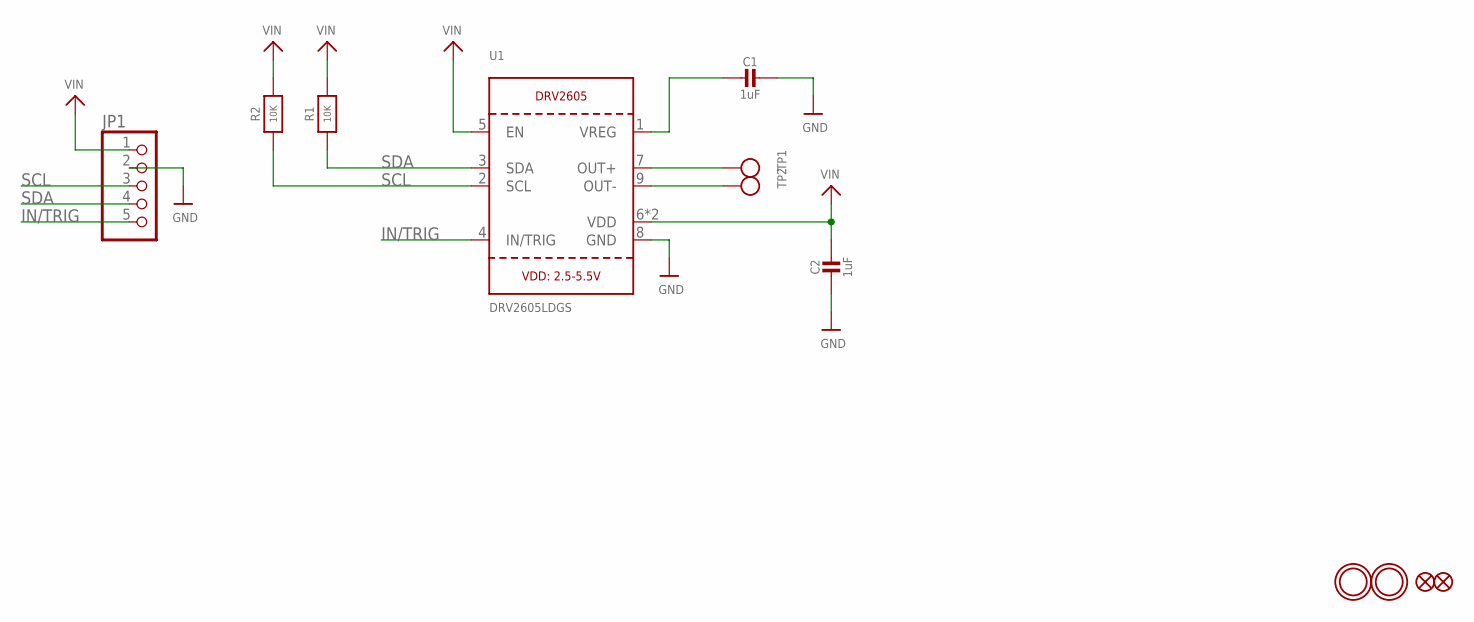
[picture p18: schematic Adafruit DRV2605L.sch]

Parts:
C1, C2: 1uF; 0805-NO
FID1, FID2: FIDUCIAL""; FIDUCIAL_1MM
JP1: HEADER-1X576MIL_FULL; 1X05_ROUND_FULL_76
R1, R2: 10K; 0805-NO
TP1, TP2: TESTPOINTPAD2MM; TESTPOINT_PAD_2MM
U1: DRV2605LDGS; PSOP10
U$2, U$3: MOUNTINGHOLE2.5; MOUNTINGHOLE_2.5_PLATED

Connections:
GND: C1.1, C2.2, JP1.2, U1.8 (GND)
IN/TRIG: JP1.5, U1.4 (IN/TRIG)
unnamed: C1.2, U1.1 (VREG)
OUT+: TP1.P$1, U1.7 (OUT+)
OUT-: TP2.P$1, U1.9 (OUT-)
SCL: JP1.3, R2.1, U1.2 (SCL)
SDA: JP1.4, R1.1, U1.3 (SDA)
VIN: C2.1, JP1.1, R1.2, R2.2, U1.5 (EN), U1.6 (VDD), U1.10 (VDD)

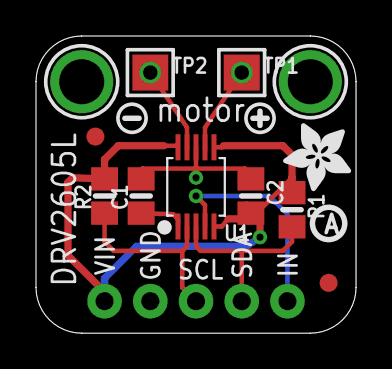
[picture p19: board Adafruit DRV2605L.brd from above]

Board: 2 copper layers, 17.8 x 16.5 mm, 16 parts (0 on the bottom side), 8 nets.

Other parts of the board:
U$4: SYMBOL_PLUS
U$5: SYMBOL_MINUS
U$15: PCBFEAT-REV-040
U$18: ADAFRUIT_3.5MM

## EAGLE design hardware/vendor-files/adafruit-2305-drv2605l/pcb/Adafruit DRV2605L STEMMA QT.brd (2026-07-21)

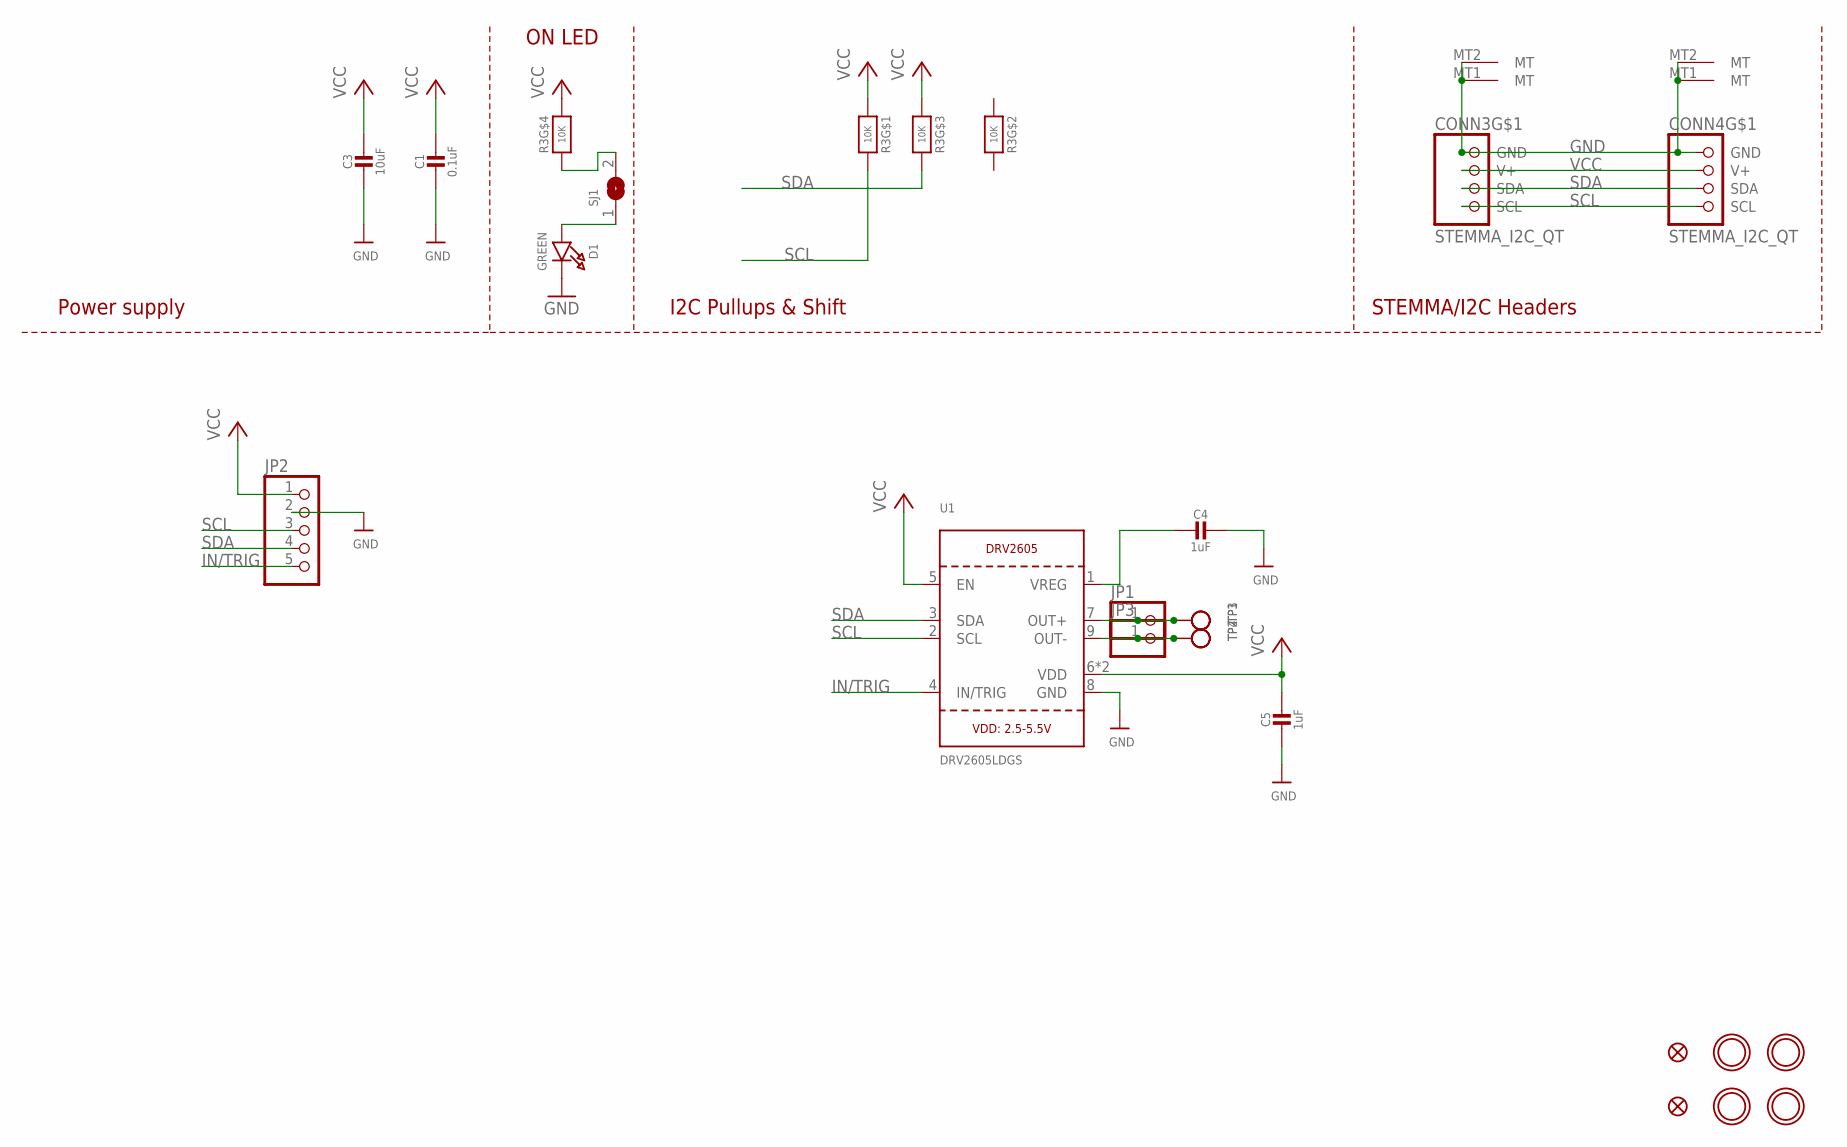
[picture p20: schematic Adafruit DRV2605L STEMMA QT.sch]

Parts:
C1: 0.1uF; 0603-NO
C3: 10uF; 0805-NO
C4, C5: 1uF; 0603-NO
CONN3, CONN4: STEMMA_I2C_QT; JST_SH4
D1: GREEN; CHIPLED_0603_NOOUTLINE
FID3, FID4: FIDUCIAL_1MM
JP1, JP3: HEADER-1X1; 1X01_OVAL
JP2: HEADER-1X576MIL; 1X05_ROUND_76
R3: 10K; RESPACK_4X0603
SJ1: SOLDERJUMPERCLOSED; SOLDERJUMPER_CLOSEDWIRE
TP1, TP2, TP3, TP4: TESTPOINTPAD2MM; TESTPOINT_PAD_2MM
U1: DRV2605LDGS; PSOP10
U$1, U$17, U$19, U$21: MOUNTINGHOLE2.5; MOUNTINGHOLE_2.5_PLATED

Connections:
GND: C1.2, C3.2, C4.1, C5.2, CONN3.1 (GND), CONN3.MT1 (MT), CONN3.MT2 (MT), CONN4.1 (GND), CONN4.MT1 (MT), CONN4.MT2 (MT), D1.C, JP2.2, U1.8 (GND)
IN/TRIG: JP2.5, U1.4 (IN/TRIG)
unnamed: R3.4 (1), SJ1.2
unnamed: D1.A, SJ1.1
unnamed: C4.2, U1.1 (VREG)
OUT+: JP1.1, TP1.P$1, TP3.P$1, U1.7 (OUT+)
OUT-: JP3.1, TP2.P$1, TP4.P$1, U1.9 (OUT-)
SCL: CONN3.4 (SCL), CONN4.4 (SCL), JP2.3, R3.8 (2), U1.2 (SCL)
SDA: CONN3.3 (SDA), CONN4.3 (SDA), JP2.4, R3.6 (2), U1.3 (SDA)
VCC: C1.1, C3.1, C5.1, CONN3.2 (V+), CONN4.2 (V+), JP2.1, R3.1, R3.3 (1), R3.5 (2), U1.5 (EN), U1.6 (VDD), U1.10 (VDD)

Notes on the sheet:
I2C Pullups & Shift
STEMMA/I2C Headers
ON LED
Power supply

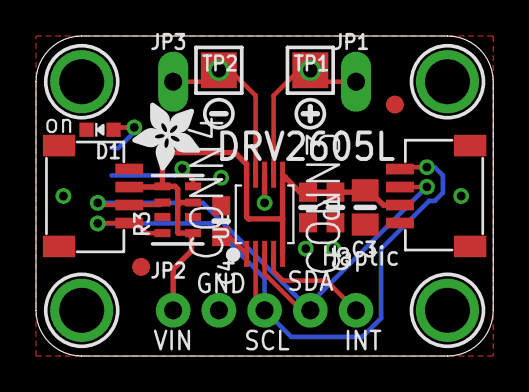
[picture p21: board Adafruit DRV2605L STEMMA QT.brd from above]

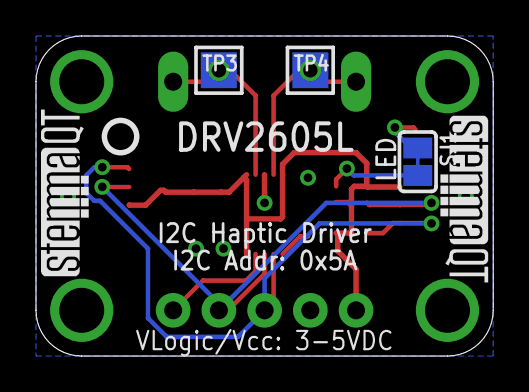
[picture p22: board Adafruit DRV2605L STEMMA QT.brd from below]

Board: 2 copper layers, 25.4 x 17.8 mm, 29 parts (6 on the bottom side), 10 nets.

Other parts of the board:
U$2: SYMBOL_PLUS
U$3: SYMBOL_MINUS
U$22: ADAFRUIT_3.5MM
U$25: PCBFEAT-REV-040
U$30, U$31: STEMMAQT

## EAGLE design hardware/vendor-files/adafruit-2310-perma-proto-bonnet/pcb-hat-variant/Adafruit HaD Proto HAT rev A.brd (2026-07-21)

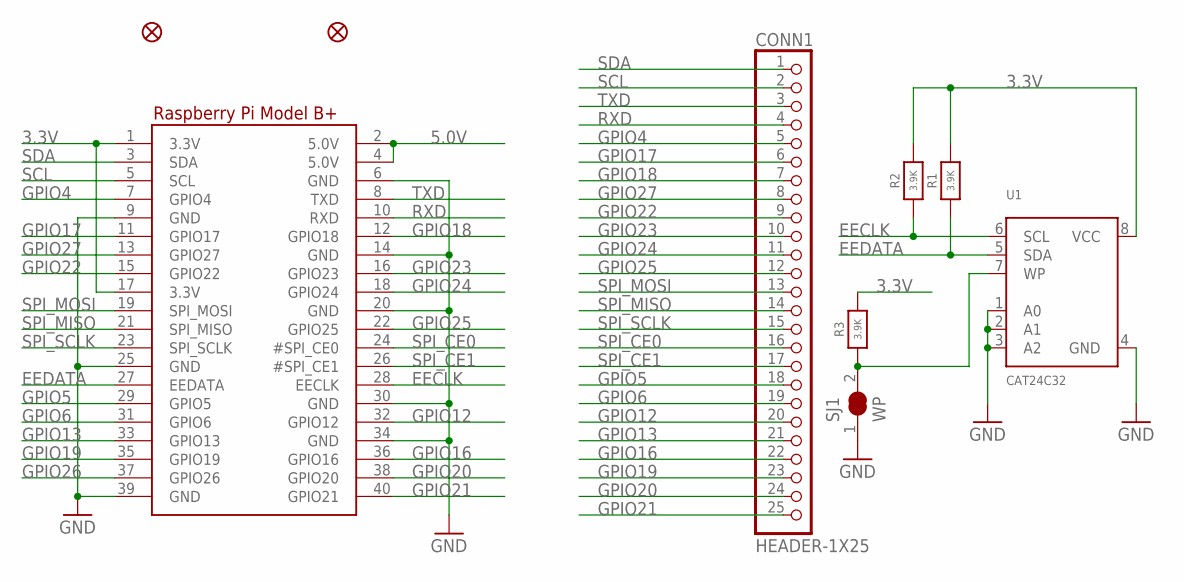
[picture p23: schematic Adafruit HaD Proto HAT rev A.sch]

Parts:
CONN1: HEADER-1X25; 1X25_ROUND_70MIL
FID2, FID3: FIDUCIAL""; FIDUCIAL_1MM
R1, R2, R3: 3.9K; 0805-NO
RPI1: RASPBERRYPI_BPLUS_HATNOSLOTS; PI_HAT_NOSLOTS
SJ1: WP; SOLDERJUMPER_CLOSEDWIRE
U1: CAT24C32; SOIC8_150MIL

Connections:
3.3V: R1.2, R2.2, R3.2, RPI1.1 (3.3V), RPI1.17 (3.3V), U1.8 (VCC)
5.0V: RPI1.2 (5.0V), RPI1.4 (5.0V)
EECLK: R2.1, RPI1.28 (EECLK), U1.6 (SCL)
EEDATA: R1.1, RPI1.27 (EEDATA), U1.5 (SDA)
GND: RPI1.6 (GND), RPI1.9 (GND), RPI1.14 (GND), RPI1.20 (GND), RPI1.25 (GND), RPI1.30 (GND), RPI1.34 (GND), RPI1.39 (GND), SJ1.1, U1.1 (A0), U1.2 (A1), U1.3 (A2), U1.4 (GND)
GPIO4: CONN1.5, RPI1.7 (GPIO4)
GPIO5: CONN1.18, RPI1.29 (GPIO5)
GPIO6: CONN1.19, RPI1.31 (GPIO6)
GPIO12: CONN1.20, RPI1.32 (GPIO12)
GPIO13: CONN1.21, RPI1.33 (GPIO13)
GPIO16: CONN1.22, RPI1.36 (GPIO16)
GPIO17: CONN1.6, RPI1.11 (GPIO17)
GPIO18: CONN1.7, RPI1.12 (GPIO18)
GPIO19: CONN1.23, RPI1.35 (GPIO19)
GPIO20: CONN1.24, RPI1.38 (GPIO20)
GPIO21: CONN1.25, RPI1.40 (GPIO21)
GPIO22: CONN1.9, RPI1.15 (GPIO22)
GPIO23: CONN1.10, RPI1.16 (GPIO23)
GPIO24: CONN1.11, RPI1.18 (GPIO24)
GPIO25: CONN1.12, RPI1.22 (GPIO25)
GPIO26: RPI1.37 (GPIO26)
GPIO27: CONN1.8, RPI1.13 (GPIO27)
unnamed: R3.1, SJ1.2, U1.7 (WP)
RXD: CONN1.4, RPI1.10 (RXD)
SCL: CONN1.2, RPI1.5 (SCL)
SDA: CONN1.1, RPI1.3 (SDA)
SPI_CE0: CONN1.16, RPI1.24 (#SPI_CE0)
SPI_CE1: CONN1.17, RPI1.26 (#SPI_CE1)
SPI_MISO: CONN1.14, RPI1.21 (SPI_MISO)
SPI_MOSI: CONN1.13, RPI1.19 (SPI_MOSI)
SPI_SCLK: CONN1.15, RPI1.23 (SPI_SCLK)
TXD: CONN1.3, RPI1.8 (TXD)

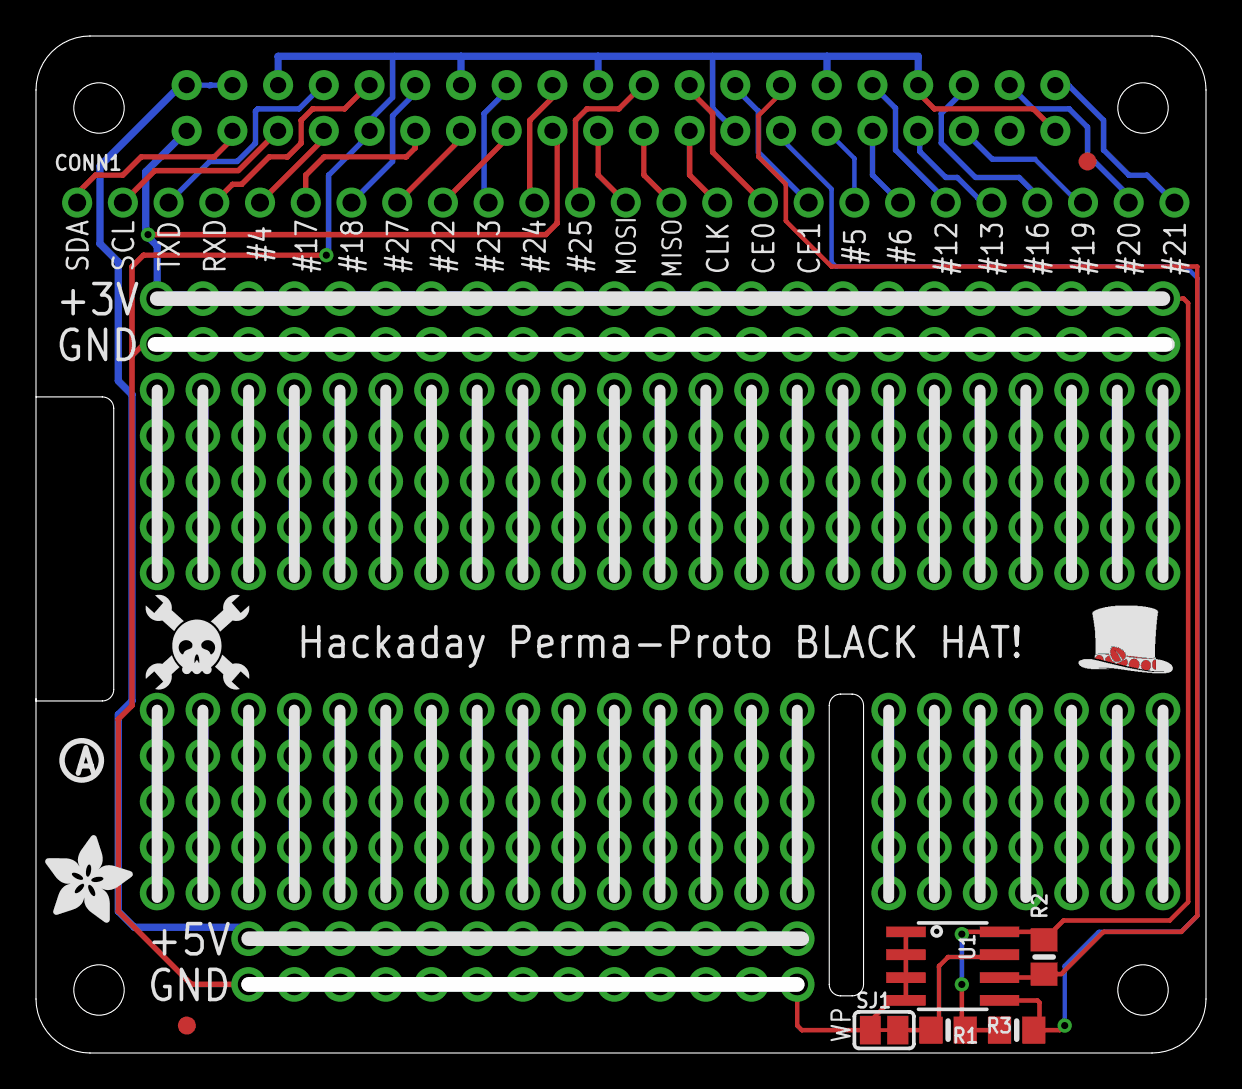
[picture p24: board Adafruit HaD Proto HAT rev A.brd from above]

Board: 2 copper layers, 65.0 x 56.5 mm, 13 parts (0 on the bottom side), 31 nets.

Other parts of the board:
U$1: ADAFRUIT_5MM
U$2: PIHATLOGO
U$3: PCBFEAT-REV-056
U$5: HAD_LOGO_200MIL

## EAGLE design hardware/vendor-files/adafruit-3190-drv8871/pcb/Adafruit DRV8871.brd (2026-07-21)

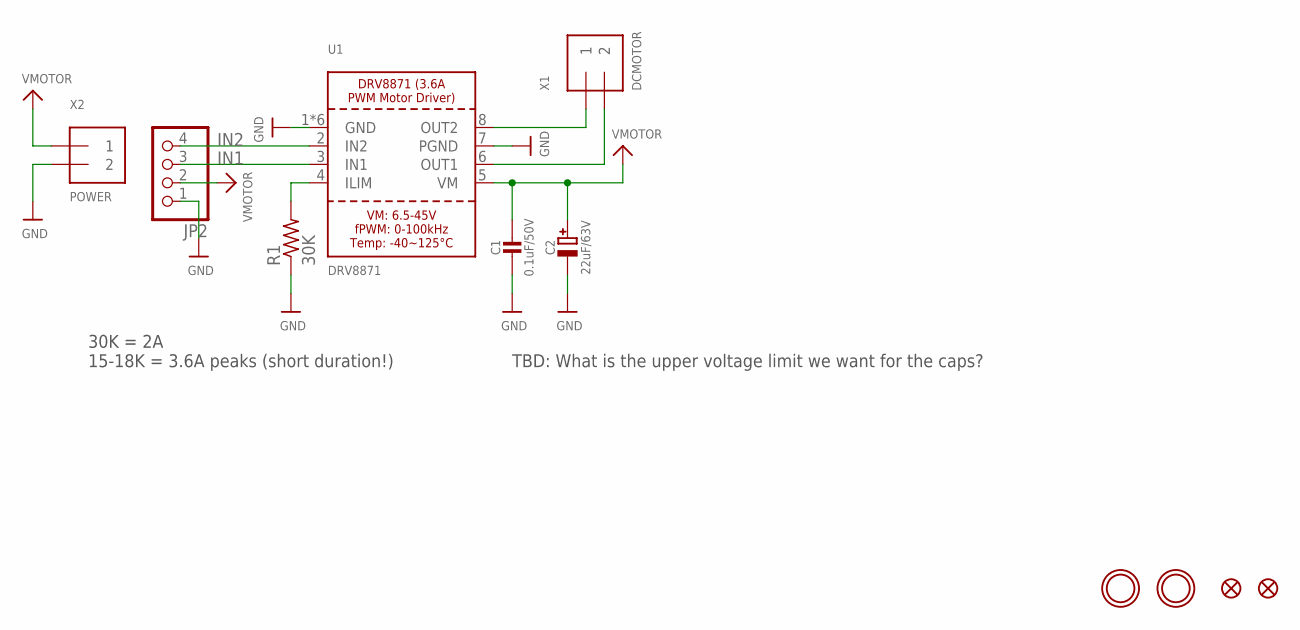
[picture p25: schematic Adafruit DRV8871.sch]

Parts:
C1: 0.1uF/50V; 0805-NO
C2: 22uF/63V; PANASONIC_D
FID1, FID2: FIDUCIAL""; FIDUCIAL_1MM
JP2: HEADER-1X476MIL; 1X04_ROUND_76
R1: 30K; 0805-THM
U1: DRV8871; HSOP8
U$9, U$10: MOUNTINGHOLE2.5; MOUNTINGHOLE_2.5_PLATED
X1: DCMOTOR; TERMBLOCK_1X2-3.5MM
X2: POWER; TERMBLOCK_1X2-3.5MM

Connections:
GND: C1.2, C2.-, JP2.1, R1.1, U1.1 (GND), U1.7 (PGND), U1.GND, U1.P$1 (GND), U1.P$2 (GND), U1.P$3 (GND), U1.P$4 (GND), X2.2
IN1: JP2.3, U1.3 (IN1)
IN2: JP2.4, U1.2 (IN2)
unnamed: R1.2, U1.4 (ILIM)
OUT1: U1.6 (OUT1), X1.2
OUT2: U1.8 (OUT2), X1.1
VMOTOR: C1.1, C2.+, JP2.2, U1.5 (VM), X2.1

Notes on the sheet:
TBD: What is the upper voltage limit we want for the caps?
30K = 2A 15-18K = 3.6A peaks (short duration!)

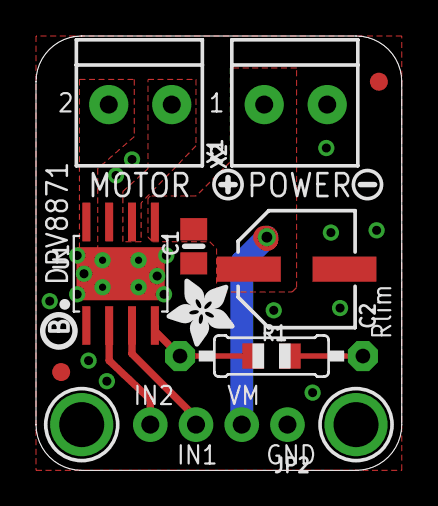
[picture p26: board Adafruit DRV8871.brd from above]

Board: 2 copper layers, 20.3 x 24.1 mm, 15 parts (0 on the bottom side), 7 nets.

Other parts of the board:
U$11: SYMBOL_PLUS
U$12: SYMBOL_MINUS
U$14: ADAFRUIT_3.5MM
U$15: PCBFEAT-REV-040

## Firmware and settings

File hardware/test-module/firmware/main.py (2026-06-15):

"""Powder-doser test-rig firmware (MicroPython, Raspberry Pi Pico W).

This is the multi-channel REPL ``main.py`` for the bench rig described
in ``hardware/test-module/README.md``.  It brings up the four actuators
(stepper, ERM coin via DRV2605L, solenoid via DRV8871, dispensing-angle
servo) and exposes a one-line-per-command serial REPL so the bench
operator can exercise any single channel while the others stay idle.

Target stack
------------
* MicroPython 1.22+ for the Raspberry Pi Pico W (RP2040 + CYW43439).
* Edited and run from VS Code via the **MicroPico** extension
  ( https://marketplace.visualstudio.com/items?itemName=paulober.pico-w-go ).
  MicroPico uploads this file as ``main.py`` and gives you a built-in
  terminal that's already wired to the Pico's USB-CDC serial port, so
  the keyboard-driven test scripts in ``tests/`` work without any extra
  terminal program.

Every pin we use is in the GP0..GP15 range, which is identical on the
plain Pico and the Pico W; the Pico W's wireless module owns
GP23/24/25/29 internally, none of which are wired here, so the same
firmware runs unmodified on either board.

Tunables live in ``config.py``; the MicroPico "Run" button re-uploads
and re-runs in a second, so edit-save-run stays quick.

Required modules on the Pico (upload alongside this file):
  - ``config.py``   (next to this file)
  - ``drv2605.py``  (next to this file)
  - ``tic.py``      (next to this file -- Tic T500 serial driver)

Wire-on commands (one per line over USB-serial):
    h            help
    s            print current state / config
    d            dispense (run auger STEPPER_DISPENSE_DEG)
    r <deg>      rotate auger by <deg> degrees (signed)
    v            vibrate (single canned effect)
    t            tap (run TAP_COUNT solenoid pulses)
    a <deg>      smoothly move dispensing-angle servo to <deg>
    p <name>     smoothly move servo to a preset (horizontal/tilt/vertical/tip)
    !            emergency stop -- de-energise everything
"""

import sys
import time

from machine import I2C, Pin, PWM, UART

import config
import tic

# Module-level poll object for MicroPython (functions can't have new
# attributes on MicroPython function objects). See _readline_nonblocking.
_readline_poll = None


# ---------------------------------------------------------------------------
# Low-level driver helpers
# ---------------------------------------------------------------------------

def _out(pin_num, value=0):
    return Pin(pin_num, Pin.OUT, value=value)


def _pwm(pin_num, freq, duty=0.0):
    pwm = PWM(Pin(pin_num))
    pwm.freq(freq)
    pwm.duty_u16(int(max(0.0, min(1.0, duty)) * 65535))
    return pwm


# ---------------------------------------------------------------------------
# Stepper (Pololu Tic T500 over TTL serial -> NEMA-11)
#
# The Pico W no longer bit-bangs STEP/DIR; it sends serial commands to the
# Tic T500, whose on-board MCU runs the motion planner (accel/decel ramps)
# and current limiting.  We keep a local shadow of the target position in
# microsteps so ``rotate_degrees`` can issue relative moves and estimate
# move durations -- the Tic's position telemetry proved unreliable on the
# bench rig, so the firmware does not read it back (see ``_wait_estimated_time``).
# ---------------------------------------------------------------------------

class Stepper:
    def __init__(self):
        self.uart = UART(config.TIC_UART_ID, baudrate=config.TIC_BAUD,
                         tx=Pin(config.PIN_TIC_TX), rx=Pin(config.PIN_TIC_RX),
                         timeout=config.TIC_READ_TIMEOUT_MS)
        self.tic = tic.TicSerial(self.uart)
        self.steps_per_rev = (config.STEPPER_FULL_STEPS_REV
                              * config.STEPPER_MICROSTEPS)
        # Shadow target position (microsteps); the Tic starts at 0 once we
        # call halt_and_set_position below.
        self._position = 0
        self._rpm = float(config.STEPPER_SPEED_RPM)
        self._enabled = False
        self._configure()

    def _accel_units(self):
        # Tic acceleration unit = 1/100 microstep per second per second.
        usteps_per_s2 = config.STEPPER_ACCEL_REV_PER_S2 * self.steps_per_rev
        return max(1, int(usteps_per_s2 * 100))

    def _configure(self):
        t = self.tic
        # Bring the driver out of any latched error/safe-start state, push
        # the motion settings the firmware owns, and zero the position.
        t.exit_safe_start()
        t.clear_driver_error()
        t.set_step_mode(config.STEPPER_MICROSTEPS)
        self.set_speed(config.STEPPER_SPEED_RPM)
        accel = self._accel_units()
        t.set_max_accel(accel)
        t.set_max_decel(accel)
        t.halt_and_set_position(0)
        self._position = 0

    def set_speed(self, rpm):
        # Tic speed unit = 1/10000 microstep per second.
        self._rpm = float(rpm)
        usteps_per_s = rpm / 60.0 * self.steps_per_rev
        self.tic.set_max_speed(max(1, int(usteps_per_s * 10000)))

    def enable(self, on=True):
        if on:
            self.tic.energize()
            self.tic.exit_safe_start()
        else:
            self.tic.deenergize()
        self._enabled = on

    def rotate_degrees(self, degrees):
        signed = degrees * (1 if config.STEPPER_DIRECTION >= 0 else -1)
        delta = int(round(signed / 360.0 * self.steps_per_rev))
        if delta == 0:
            return
        if not self._enabled:
            self.enable(True)
        self._position += delta
        self.tic.set_target_position(self._position)
        self._wait_estimated_time(delta)

    def _wait_estimated_time(self, delta):
        # The Tic T500's TX line proved unreliable at reporting position
        # back to the Pico on the bench rig, so instead of polling
        # ``current_position()`` we wait an estimated time based on the
        # commanded microstep delta and the current speed.  We still ping
        # the Tic's command-timeout watchdog throughout so a long move
        # isn't cut short.  Position is tracked locally (``self._position``);
        # missed steps go undetected, which is acceptable for auger
        # rotation where exact position isn't critical.
        usteps_per_s = max(1.0, self._rpm / 60.0 * self.steps_per_rev)
        est_s = abs(delta) / usteps_per_s + 0.2
        deadline = time.ticks_add(time.ticks_ms(), int(est_s * 1000) + 2000)
        while time.ticks_diff(deadline, time.ticks_ms()) > 0:
            try:
                self.tic.reset_command_timeout()
            except Exception:
                pass
            time.sleep_ms(50)


# ---------------------------------------------------------------------------
# Vibration (DRV2605L)
# ---------------------------------------------------------------------------

class Vibration:
    def __init__(self):
        self.enable_pin = _out(config.PIN_HAPT_EN, 1)
        try:
            import drv2605
            self.i2c = I2C(0, scl=Pin(config.PIN_I2C_SCL),
                              sda=Pin(config.PIN_I2C_SDA),
                              freq=400_000)
            self.drv = drv2605.DRV2605(self.i2c)
            self.drv.library = config.VIBRATION_LIBRARY
            self.drv.effect = config.VIBRATION_EFFECT_ID
            self._available = True
        except Exception as exc:
            print("[vib] DRV2605L unavailable ({}); skipping init".format(exc))
            self._available = False

    def buzz(self, duration_s=None):
        if not self._available:
            print("[vib] driver missing -- ignoring buzz")
            return
        seconds = (config.VIBRATION_DURATION_S
                   if duration_s is None else duration_s)
        self.enable_pin.value(1)
        self.drv.play()
        time.sleep(seconds)
        self.drv.stop()


# ---------------------------------------------------------------------------
# Tap (DRV8871 + solenoid).  IN1 PWM, IN2 low gives forward-drive with
# coil-side flyback handled internally by the DRV8871.
# ---------------------------------------------------------------------------

class Tap:
    def __init__(self):
        # 20 kHz PWM is above audible, well within DRV8871's input filter.
        self.in1 = _pwm(config.PIN_SOL_IN1, freq=20_000, duty=0.0)
        self.in2 = _out(config.PIN_SOL_IN2, 0)

    def _on(self, duty):
        self.in2.value(0)
        self.in1.duty_u16(int(max(0.0, min(1.0, duty)) * 65535))

    def _off(self):
        self.in1.duty_u16(0)

    def tap(self, count=None):
        n = config.TAP_COUNT if count is None else count
        for _ in range(n):
            self._on(config.TAP_PWM_DUTY)
            time.sleep_ms(config.TAP_ON_MS)
            self._off()
            time.sleep_ms(config.TAP_OFF_MS)


# ---------------------------------------------------------------------------
# Dispensing-angle servo (hobby servo on Pico GPIO via 50 Hz PWM).
# ---------------------------------------------------------------------------

class Servo:
    """Hobby servo with smooth interpolated motion.

    Every angle command is ramped from the current position to the
    target at ``config.SERVO_SPEED_DEG_PER_S`` deg/s, updated at
    ``config.SERVO_UPDATE_HZ`` Hz.  This avoids the violent "snap" you
    get from writing the new pulse width in a single PWM frame, which
    is important on the powder-doser dispense axis to keep loose powder
    from jumping out of the cup.
    """

    PERIOD_US = 20_000  # 50 Hz

    def __init__(self):
        self.pwm = _pwm(config.PIN_SERVO_SIG, freq=50, duty=0.0)
        self.angle = float(config.SERVO_DEFAULT_DEG)
        # Seed the PWM at the default angle so the servo doesn't jump
        # from 0 on its first interpolated move.
        self._write_angle(self.angle)
        # Re-issue through the smooth path so a freshly powered (but
        # already-centred) servo still ramps gently into position.
        self.move_to(config.SERVO_DEFAULT_DEG)

    def _write_angle(self, angle_deg):
        span = config.SERVO_MAX_ANGLE_DEG - config.SERVO_MIN_ANGLE_DEG
        frac = ((angle_deg - config.SERVO_MIN_ANGLE_DEG) / span
                if span else 0)
        pulse_us = (config.SERVO_MIN_PULSE_US
                    + frac * (config.SERVO_MAX_PULSE_US
                              - config.SERVO_MIN_PULSE_US))
        duty = pulse_us / self.PERIOD_US
        self.pwm.duty_u16(int(duty * 65535))

    def move_to(self, angle_deg):
        target = max(config.SERVO_MIN_ANGLE_DEG,
                     min(config.SERVO_MAX_ANGLE_DEG, angle_deg))
        speed = float(config.SERVO_SPEED_DEG_PER_S)
        if speed <= 0:
            self._write_angle(target)
            self.angle = target
            return
        update_hz = max(1, config.SERVO_UPDATE_HZ)
        step_deg = speed / update_hz
        dt = 1.0 / update_hz
        delta = target - self.angle
        if abs(delta) <= step_deg:
            self._write_angle(target)
            self.angle = target
            return
        step = step_deg if delta > 0 else -step_deg
        while abs(target - self.angle) > step_deg:
            self.angle += step
            self._write_angle(self.angle)
            time.sleep(dt)
        self._write_angle(target)
        self.angle = target


# ---------------------------------------------------------------------------
# Top-level test rig
# ---------------------------------------------------------------------------

HELP = (
    "Commands:\n"
    "  h            show this help\n"
    "  s            print rig state / config\n"
    "  d            dispense (rotate auger STEPPER_DISPENSE_DEG)\n"
    "  r <deg>      rotate auger by <deg> (signed)\n"
    "  v            vibrate (single canned effect)\n"
    "  t            tap (TAP_COUNT solenoid pulses)\n"
    "  a <deg>      servo to <deg>\n"
    "  p <preset>   servo to named preset\n"
    "  !            emergency stop\n"
)


class Rig:
    def __init__(self):
        print("[rig] bringing up powder-doser test module")
        self.stepper = Stepper()
        self.vib = Vibration()
        self.tap = Tap()
        self.servo = Servo()
        print("[rig] ready -- type 'h' for help")

    def state(self):
        print(
            "stepper: rpm={rpm}, microsteps=1/{ms}, steps/rev={spr}, "
            "dispense_deg={dd}".format(
                rpm=config.STEPPER_SPEED_RPM,
                ms=config.STEPPER_MICROSTEPS,
                spr=self.stepper.steps_per_rev,
                dd=config.STEPPER_DISPENSE_DEG,
            ))
        print(
            "vib: effect={eff} (lib={lib}), duration={dur}s".format(
                eff=config.VIBRATION_EFFECT_ID,
                lib=config.VIBRATION_LIBRARY,
                dur=config.VIBRATION_DURATION_S,
            ))
        print(
            "tap: count={c}, on={on}ms, off={off}ms, duty={d}".format(
                c=config.TAP_COUNT,
                on=config.TAP_ON_MS,
                off=config.TAP_OFF_MS,
                d=config.TAP_PWM_DUTY,
            ))
        print(
            "servo: angle={a:.1f}, range=[{lo}..{hi}], "
            "speed={s} deg/s, presets={p}".format(
                a=self.servo.angle,
                lo=config.SERVO_MIN_ANGLE_DEG,
                hi=config.SERVO_MAX_ANGLE_DEG,
                s=config.SERVO_SPEED_DEG_PER_S,
                p=list(config.SERVO_PRESETS),
            ))

    def emergency_stop(self):
        print("[rig] EMERGENCY STOP")
        self.stepper.enable(False)
        self.tap._off()
        if self.vib._available:
            try:
                self.vib.drv.stop()
            except Exception:
                pass
            self.vib.enable_pin.value(0)

    def handle(self, line):
        line = line.strip()
        if not line:
            return
        cmd, _, arg = line.partition(" ")
        cmd = cmd.lower()
        try:
            if cmd in ("h", "?", "help"):
                print(HELP)
            elif cmd == "s":
                self.state()
            elif cmd == "d":
                self.stepper.rotate_degrees(config.STEPPER_DISPENSE_DEG)
            elif cmd == "r":
                self.stepper.rotate_degrees(float(arg))
            elif cmd == "v":
                self.vib.buzz()
            elif cmd == "t":
                self.tap.tap()
            elif cmd == "a":
                self.servo.move_to(float(arg))
            elif cmd == "p":
                if arg not in config.SERVO_PRESETS:
                    print("unknown preset {!r}; choose from {}".format(
                        arg, list(config.SERVO_PRESETS)))
                    return
                self.servo.move_to(config.SERVO_PRESETS[arg])
            elif cmd in ("!", "stop"):
                self.emergency_stop()
            else:
                print("unknown command {!r}; 'h' for help".format(cmd))
        except Exception as exc:
            print("[rig] command failed: {!r}".format(exc))


def _readline_nonblocking(buf=[""]):
    """Buffer characters from stdin until a newline arrives.

    Uses ``uselect.poll()`` on ``sys.stdin`` (MicroPython) so the main
    loop doesn't block while waiting for the operator to finish typing
    the next command.
    """
    global _readline_poll
    try:
        import uselect
    except ImportError:
        # CPython fallback (no non-blocking stdin): just read a line.
        return sys.stdin.readline().rstrip("\r\n")
    if _readline_poll is None:
        _readline_poll = uselect.poll()
        _readline_poll.register(sys.stdin, uselect.POLLIN)
    if not _readline_poll.poll(0):
        return None
    ch = sys.stdin.read(1)
    if ch in ("\r", "\n"):
        line, buf[0] = buf[0], ""
        return line
    buf[0] += ch
    return None


def main():
    rig = Rig()
    rig.state()
    while True:
        line = _readline_nonblocking()
        if line is not None:
            rig.handle(line)
        time.sleep_ms(10)


if __name__ == "__main__":
    main()

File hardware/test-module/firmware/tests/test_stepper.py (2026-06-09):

"""Stepper-motor (Pololu Tic T500 + NEMA-11) standalone test (MicroPython).

Pin assignments are imported from ``config.py``, which is also the
contract the KiCad schematic is generated from -- so this script and
the full rig firmware stay in lockstep.  Only the stepper channel is
exercised; everything else (haptic, solenoid, servo) is untouched.

The auger is driven through a Pololu Tic T500 over UART (TTL serial):
this script opens the same UART1 the main firmware uses and sends the
Tic serial commands via the shared ``tic.TicSerial`` driver.  Set the
Tic's current limit and "Control mode = Serial / I2C / USB" once with
the Tic Control Center over USB before running this (and disable the
Tic's "Command timeout" so a long move isn't cut short).

To run on the Pico W from VS Code + MicroPico:

1. Upload the firmware folder once ("Upload project" in MicroPico).
2. Open this file and hit MicroPico's "Run current file on Pico"
   (the green play arrow in the status bar) -- it streams stdout to
   the built-in terminal and feeds your keystrokes into ``sys.stdin``.

Keyboard controls (single keystroke; no Enter needed):
    space   step DEFAULT_MOVE_DEG in the current direction
    f       one full revolution (360 deg)
    r       reverse the direction flag
    +       speed up by SPEED_STEP_RPM
    -       slow down by SPEED_STEP_RPM
    e       toggle energise (drive de-energised vs. holding torque)
    s       print state
    q       quit (de-energise and exit the loop)
"""

import sys
import time

# Allow `python tests/test_stepper.py` style invocation from the
# firmware/ folder root by making the parent dir importable.
sys.path.insert(0, "..")
sys.path.insert(0, "/")

from machine import Pin, UART

import config
import tic
from tests._keypress import read_key


# ---------------------------------------------------------------------------
# Adjustable test parameters (independent of the main rig config).
# ---------------------------------------------------------------------------
DEFAULT_MOVE_DEG = 90.0      # how far each spacebar press rotates
SPEED_STEP_RPM   = 10        # +/- adjustment granularity
START_DIRECTION  = +1        # +1 = CW from motor face, -1 = CCW


class StepperTest:
    def __init__(self):
        self.uart = UART(config.TIC_UART_ID, baudrate=config.TIC_BAUD,
                         tx=Pin(config.PIN_TIC_TX), rx=Pin(config.PIN_TIC_RX),
                         timeout=config.TIC_READ_TIMEOUT_MS)
        self.tic = tic.TicSerial(self.uart)
        self.steps_per_rev = (config.STEPPER_FULL_STEPS_REV
                              * config.STEPPER_MICROSTEPS)
        self.rpm = float(config.STEPPER_SPEED_RPM)
        self.direction = +1 if START_DIRECTION >= 0 else -1
        self.enabled = False
        self._position = 0
        # Bring the Tic up, push step mode / speed / accel, zero position.
        self.tic.exit_safe_start()
        self.tic.clear_driver_error()
        self.tic.set_step_mode(config.STEPPER_MICROSTEPS)
        self._apply_speed()
        accel = max(1, int(config.STEPPER_ACCEL_REV_PER_S2
                           * self.steps_per_rev * 100))
        self.tic.set_max_accel(accel)
        self.tic.set_max_decel(accel)
        self.tic.halt_and_set_position(0)

    def _apply_speed(self):
        usteps_per_s = self.rpm / 60.0 * self.steps_per_rev
        self.tic.set_max_speed(max(1, int(usteps_per_s * 10000)))

    def enable(self, on=True):
        if on:
            self.tic.energize()
            self.tic.exit_safe_start()
        else:
            self.tic.deenergize()
        self.enabled = on

    def set_rpm(self, rpm):
        self.rpm = max(1.0, rpm)
        self._apply_speed()

    def rotate(self, degrees):
        signed = degrees * self.direction
        delta = int(round(signed / 360.0 * self.steps_per_rev))
        if delta == 0:
            return
        if not self.enabled:
            self.enable(True)
        # update our local position estimate
        self._position += delta
        # tell the Tic the new target
        self.tic.set_target_position(self._position)
        # wait an estimated time for the move to complete (no telemetry required)
        self._wait_estimated_time(delta)

    def _wait_estimated_time(self, delta):
        """Wait based on commanded microstep delta and current RPM.
        This does not read the Tic's telemetry; it only keeps the Tic's
        command timeout alive while waiting.
        """
        # usteps_per_s = microsteps/second based on current rpm & steps_per_rev
        usteps_per_s = max(1.0, self.rpm / 60.0 * self.steps_per_rev)
        est_s = abs(delta) / usteps_per_s
        # add a safety margin
        est_s += 0.2
        # cap very small waits to a short sleep to avoid busy-looping
        wait_ms = int(est_s * 1000)
        # keep resetting Tic command timeout during the wait in small chunks
        deadline = time.ticks_add(time.ticks_ms(), wait_ms + 2000)
        while time.ticks_diff(deadline, time.ticks_ms()) > 0:
            # keep Tic from timing out (the Tic stops if it doesn't see timeout reset)
            try:
                self.tic.reset_command_timeout()
            except Exception:
                # be defensive: ignore if reset_command_timeout doesn't reply
                pass
            # sleep in small increments so we can service KeyboardInterrupt in interactive tests
            time.sleep_ms(50)

    def state(self):
        return ("stepper: rpm={:.1f}, dir={:+d}, microsteps=1/{}, "
                "steps/rev={}, enabled={}").format(
                    self.rpm, self.direction,
                    config.STEPPER_MICROSTEPS,
                    self.steps_per_rev, self.enabled)


HELP = (
    "Stepper test (Tic T500) -- keyboard controls:\n"
    "  space  rotate {move} deg\n"
    "  f      one full revolution (360 deg)\n"
    "  r      reverse direction\n"
    "  +/-    adjust RPM by {step}\n"
    "  e      toggle energise (holding torque on/off)\n"
    "  s      print state\n"
    "  q      quit\n"
).format(move=DEFAULT_MOVE_DEG, step=SPEED_STEP_RPM)
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

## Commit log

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2026-05-07 Cite official Bambu Studio Command-Line Usage wiki for STL slicing
    Agent-Logs-Url: https://github.com/vertical-cloud-lab/powder-doser/sessions/2a32aaac-6e76-4ec3-bc24-73219d04b32d
2026-05-07 Add empirically verified Bambu Studio CLI walkthrough (STL → 3MF)
    Agent-Logs-Url: https://github.com/vertical-cloud-lab/powder-doser/sessions/f24f2bbf-d39a-437b-99e0-9117eae8059d
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2026-05-07 Add bringup checklist for connecting to a real H2D printer
    Agent-Logs-Url: https://github.com/vertical-cloud-lab/powder-doser/sessions/b8399dc2-7f1f-4849-bd3a-26daa82c385e
2026-05-07 Add hardware parts identification doc for vibration motor and solenoid
    Agent-Logs-Url: https://github.com/vertical-cloud-lab/powder-doser/sessions/9292b4e9-092a-4c5b-bbea-c952b7f964b1
2026-05-07 Fix flyback diode orientation in ASCII schematic; prefer SS14 Schottky
    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
2026-05-07 Switch solenoid driver to pre-packaged DRV8871 + Bonnet, add block diagram
    Agent-Logs-Url: https://github.com/vertical-cloud-lab/powder-doser/sessions/4440adc7-e3c7-49be-a217-10c49e455220
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2026-05-07 Replace ASCII diagram with real KiCad schematic; address review comments
    Agent-Logs-Url: https://github.com/vertical-cloud-lab/powder-doser/sessions/4d1e1ee8-eb66-47a0-a8a2-d91d3ba9b7be
    [powder_doser_actuators.kicad_sch]
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2026-05-08 Improve KiCad schematic layout: pull global labels off symbol bodies via wire stubs
    Agent-Logs-Url: https://github.com/vertical-cloud-lab/powder-doser/sessions/e898731e-d2b1-4dbb-bfa7-52bd318030df
    [powder_doser_actuators.kicad_sch]
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2026-05-12 Add §2.2 inward-collection-cup visualization (2D sketch + CadQuery STEP/renders); incorporate sgbaird's 30-choose-6 nuance in §1
    Agent-Logs-Url: https://github.com/vertical-cloud-lab/powder-doser/sessions/7f6f8442-f5ef-465a-add9-502426f01ba9
    [inward_collection_cup.step]
2026-05-12 Revert to integrated monolithic auger (v4); scale up to 250×25 mm for H2D
    Agent-Logs-Url: https://github.com/vertical-cloud-lab/powder-doser/sessions/3172d9d7-b0b9-4737-893c-02944169e6c9
    [archimedes-auger.scad, archimedes-auger.stl, auger-housing.scad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]
2026-05-12 Address copilot-PR-reviewer feedback: fix broken cad link, DRV8871 H-bridge wording, single-supply reconciliation, ~EN logic, and kicad README
    Agent-Logs-Url: https://github.com/vertical-cloud-lab/powder-doser/sessions/ffcfffc3-2c3f-494e-bd1f-c115488ed143
2026-05-12 Fix top-cap loading slots that didn't cut through to the outside
    The four sectoral loading slots were translated to the bottom of the
    top cap with center=true, so their cube center sat 3 mm below the cap
    center and the cut never reached the top face — the rendered iso
    showed a sealed cylinder with only the M3 pilot hole. Translate to
    total_height - top_cap_height/2 so the cube straddles the cap and the
    top_cap_height + 0.2 mm Z overshoot punches fully through. STL stays
    admesh-clean (1 part, 0 disconnected, 0 degenerate, V=43.64 cm³).
    Agent-Logs-Url: https://github.com/vertical-cloud-lab/powder-doser/sessions/7743f1aa-2deb-4b7a-8878-45be36e87d4d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
    [archimedes-auger.scad, archimedes-auger.stl]
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2026-05-12 Add 3MF export for Bambu Studio import
    Agent-Logs-Url: https://github.com/vertical-cloud-lab/powder-doser/sessions/dfccf530-f556-4c56-a163-bed744a71564
    [archimedes-auger.3mf]
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2026-05-13 Add central support shaft for the helix (fixes failed inner-screw print)
    Agent-Logs-Url: https://github.com/vertical-cloud-lab/powder-doser/sessions/afdfc055-4feb-49a9-8e59-60557811a1e3
    [archimedes-auger.3mf, archimedes-auger.scad, archimedes-auger.stl]
2026-05-13 Remove inner core (helix + central shaft) per review — v5 hollow tube
    The H2D test print on 2026-05-13 succeeded for the outer tube + funnel +
    top cap but the inner helix / central shaft came out as strings. Per PR
    review: "We were able to print this without the inner core, leave the
    inner core out, and it's fine to make that 'empty core space' larger to
    reduce the cantilever effect. I don't want powder getting trapped."
    Changes:
    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
    [archimedes-auger.3mf, archimedes-auger.scad, archimedes-auger.stl]
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2026-05-14 Fix dead links flagged in PR review: discontinued LRA #1631, nonexistent psc.me.byu.edu, and malformed StepperOnline URL
    Agent-Logs-Url: https://github.com/vertical-cloud-lab/powder-doser/sessions/5c8b7fd6-cdee-4414-b813-db806f83a804
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2026-05-15 Mirror vendor CAD/PCB/drill-guide files under hardware/vendor-files/ with licenses
    Agent-Logs-Url: https://github.com/vertical-cloud-lab/powder-doser/sessions/55b6adbb-3ac9-40fc-8c05-74d943a98468
    [2305 DRV2605L.f3d, 2305 DRV2605L.step, 2305 DRV2605L.stl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]
2026-05-15 Replace OOS Adafruit #352 wall-wart with #4880 (adjustable 3-12V/5A)
    Agent-Logs-Url: https://github.com/vertical-cloud-lab/powder-doser/sessions/84d15073-e22a-49d4-a748-d84a91b6188c
2026-05-15 Manual downloads from various websites
    Via links given in https://github.com/vertical-cloud-lab/powder-doser/blob/copilot/identify-vibration-motor-solenoid-parts/hardware/vendor-files/README.md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 (permalink: https://github.com/vertical-cloud-lab/powder-doser/blob/bd53bec98f2c6d12fd68459be588aa3724cd5379/hardware/vibration-motor-and-solenoid.md)
    [11HS18-0674S.STEP, Adafruit HaD Proto HAT rev A.brd, Adafruit HaD Proto HAT rev A.sch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]
2026-05-15 Switch 12 V wall-wart to fixed-output Mean Well GST60A12-P1J on Digi-Key (drop adjustable #4880, drop pricey Pololu #1468)
    Agent-Logs-Url: https://github.com/vertical-cloud-lab/powder-doser/sessions/cf5fc152-d161-4c87-9fe0-9be8c2f98c90
2026-05-15 Organize manual-download vendor files into per-part dirs + add SPECS/SOURCES
    Agent-Logs-Url: https://github.com/vertical-cloud-lab/powder-doser/sessions/2941a6b3-14a4-43b6-b938-760bbdd1344b
    [11HS18-0674S.STEP, Adafruit HaD Proto HAT rev A.brd, Adafruit HaD Proto HAT rev A.sch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]
2026-05-15 Replace 4 small loading slots with one large opening + one-sided pour lip
    Per review comment #4464237145: "make it so there's just one opening to put
    the powder into from the top, and that it's larger so it's easier to pour
    into. Consider adding a small 'cup'-like interface or funnel of sorts (can
    be a one-side funnel, kind of like a slide) to put in. This needs to be
    relatively non-invasive and small. Even just creating a single larger
    opening will help."
    - top_cap() now cuts a single 150° pie-slice opening through the cap
    (annulus from r=4.5 mm to r=10 mm, ~250 mm² of clear pour area —
    more than 2× the v5 4-slot total in a single mouth a scoop or
    squeeze-bottle nozzle can fit s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
    [archimedes-auger.3mf, archimedes-auger.scad, archimedes-auger.stl]
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2026-06-08 Generate router-ready KiCad starter board for Quilter/DeepPCB (note 21)
    [test_module_starter.kicad_pcb]
2026-06-08 Fix return type annotations in starter-board generator
2026-06-09 Rebuild starter board with real vendor component packages (PR #25)
    [test_module_starter.kicad_pcb]
2026-06-09 Replace telemetry polling with time-based wait in test_stepper (use local position estimate)
    [test_stepper.py]
2026-06-09 Generate validated .kicad_sch schematic for starter board (Quilter/DeepPCB trio)
    [test_module_starter.kicad_sch]
2026-06-09 Address review: move imports to top, SHA-256 UUIDs, capture kicad-cli stderr
    [test_module_starter.kicad_sch]
2026-06-10 Emit KiCad 7 (20221018) .kicad_pcb so Quilter accepts the starter board
    [test_module_starter.kicad_pcb]
2026-06-10 Compact starter-board placement + emit unplaced auto-place variant trio
    [test_module_unplaced.kicad_pcb, test_module_unplaced.kicad_sch]
2026-06-10 Add Edison placement review; relax Power net-class clearance for header breakout
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2026-06-12 Fix starter-board pin counts to match real parts (Pico W 15→40, etc.)
    [test_module_starter.kicad_pcb, test_module_starter.kicad_sch, test_module_unplaced.kicad_pcb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]
2026-06-13 Swap starter-board placeholder pads for real KiCad library footprints
    [test_module_starter.kicad_pcb, test_module_starter.kicad_sch, test_module_unplaced.kicad_pcb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]
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2026-06-13 Implement Edison feedback: domain/cluster/edge-aware board placement
    [test_module_starter.kicad_pcb, test_module_unplaced.kicad_pcb]
2026-06-15 Fix MicroPython AttributeError in _readline_nonblocking by using module-level _readline_poll
    [main.py]
2026-06-16 Add Waveshare Pico-2CH-RS232 module footprint for scale integration
    [test_module_starter.kicad_pcb, test_module_starter.kicad_sch, test_module_unplaced.kicad_pcb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]
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2026-06-17 Fix Quilter schematic↔board pin-count mismatch via footprint (path)/(attr) linkage
    [test_module_starter.kicad_pcb, test_module_unplaced.kicad_pcb, test_module_unplaced.kicad_sch]
2026-06-17 Right-size unplaced board to 100x100mm; document Quilter stackup recommendation + datasheet-verification prep
    [test_module_unplaced.kicad_pcb]
2026-06-20 Fix 3D phantom-pin render for Pico/RS-232/Tic header carriers in starter board generator
    [test_module_starter.kicad_pcb, test_module_unplaced.kicad_pcb]
2026-06-20 Evaluate six Quilter-routed candidate boards; recommend Candidate 4
    [test_module_unplaced.kicad_pcb]
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2026-07-08 Align starter-board KiCad trios with PR #100 scale integration (U6 RS-232 on +3V3, SCALE_TX/RX)
    Regenerates both upload trios from PR #100's rev B netlist: the Waveshare
    Pico-2CH-RS232 becomes U6 reached via its channel-0 4-pin TTL header
    (VCC on +3V3 so the TTL swing stays inside the RP2040 abs max), wired
    straight across on UART0 (GP12->TXD = SCALE_TX, GP13<-RXD = SCALE_RX);
    the 40-pad J2 receptacle model and the spare GP8/GP9 channel nets are
    dropped. Board is now 15 footprints / 101 pads / 75 net-assigned /
    22 nets. Verified: kicad-cli netlist (75 pins, 22 nets, zero
    unconnected), pcbnew DRC (0 courtyard/clearance errors, both trios),
    15<->15 footprint<->symbol UUID bijection, byte-for-b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
    [test_module_starter.kicad_pcb, test_module_starter.kicad_sch, test_module_unplaced.kicad_pcb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]
2026-07-09 Fix U6 RS-232 module footprint: restore 2x20 receptacle (mid-body 4-pin header was unpluggable)
    @lbwinters caught that the generated layout placed the Waveshare
    Pico-2CH-RS232 module's pin holes in the middle of its 21x52 mm body,
    which would make the physical module impossible to plug in. The PR #100
    alignment had adopted that PR's bench-symbol abstraction ("only its
    4-pin TTL header reaches the Pico") literally, but the module's own
    schematic (hardware/vendor-files/waveshare-pico-2ch-rs232) shows no
    such header exists: its TTL signals live only on its 2x20
    Pico-form-factor header.
    U6 is again the 2x20 side receptacle the module actually plugs onto
    (two real PinHeader_1x20 columns at the P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
    [test_module_starter.kicad_pcb, test_module_starter.kicad_sch, test_module_unplaced.kicad_pcb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]
2026-07-09 Full physical-footprint audit: vendor-exact hole maps for all 5 carriers + barrel-jack GND fix
    Re-verified every component against primary vendor geometry (PR #25 Eagle
    .brd files, Pololu reg19a/tvs01a/tic03b dimension diagrams + official
    tic03b drill-guide DXF, CUI PJ-102AH datasheet, Waveshare module schematic,
    Pico mechanical drawing) per PR #76 review request. Fixes five unpluggable
    land patterns (Tic T500 38.1x26.7 mm with all 29 real holes and correct
    A2/A1 order; D24V22F5 17.8x17.8 mm PG/EN/VIN/GND/VOUT row + offset GND;
    shunt regulator 28.6x20.3 mm wire terminals; DRV8871 3.5 mm terminal
    blocks + 1x4 logic header; DRV2605L STEMMA QT 1x5 row with real SCL/SDA
    order, EN pin dropped as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
    [test_module_starter.kicad_pcb, test_module_starter.kicad_sch, test_module_unplaced.kicad_pcb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]
2026-07-14 Evaluate 2026-07-14 Quilter run-2 candidates: DRC + ngspice power integrity, recommend candidate 6
    Commits five of the six 7/14 candidates verbatim (candidate 4's attachment
    link is malformed) under starter_board/quilter_candidates_run2/, with a
    re-runnable analyzer (DRC, connectivity, per-net widths, placement side) and
    an upgraded ngspice IR-drop simulation (T-junction splitting, layer-aware
    node clustering, module-internal-bridge detection). Findings in note 24:
    reviewed settings fixed the run-1 thin-copper and net-0 issues; the In2
    "power plane" zone exported unnetted (all 154 DRC errors per board);
    candidates 2/5 place THT modules on the bottom side; candidate 5 routes the
    stepper's 1 A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
    [test_module_unplaced.kicad_pcb]
2026-07-15 Add second dispensing-angle servo M4 (SERVO_SIG2 on GP2) — 2-servo design alignment
    williamulbz's PR #76 review flagged that the board predates the move to
    the 2-servo design (PR #66 dual-servo hinge; PR #100 generate.py rev C).
    build_starter_board.py now emits a second 3-pin servo header M4 wired
    exactly as rev C: SIG -> SERVO_SIG2 on Pico GP2 (mirrored in firmware via
    config.SERVO2_INVERT), +5V/GND shared. M4 joins the logic/mcu placement
    cluster beside M3, edge-biased for cable exit.
    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
    [test_module_starter.kicad_pcb, test_module_starter.kicad_sch, test_module_unplaced.kicad_pcb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]
2026-07-16 Evaluate 2026-07-15 Quilter run-3 candidates (2-servo board): M4 verified, parts audit vs PR #100, ngspice PI — recommend candidate 2
    [test_module_unplaced.kicad_pcb]
2026-07-16 Apply note-25 In2 zone fix to run-3 candidate 2: <no net> zone -> GND plane
    Reassign the Quilter-exported <no net> zone on In2.Cu to GND and refill
    via pcbnew (fix_candidate2_in2_zone.py), writing the fabrication-ready
    board to candidate_2_fixed/ (verbatim candidate_2/ untouched). DRC
    clearance+hole_clearance errors 152 -> 0, unconnected ratsnest stays 0,
    In2.Cu becomes a second solid GND plane (~11,153 mm^2, matching In1.Cu).
    Captured before/after in fix_report.json + rendered In2 plane preview;
    note 25 and READMEs updated.
    [test_module_unplaced.kicad_pcb]
2026-07-16 JLCPCB ordering kit for run-3 candidate 2: final schematic sync pass + DRC gate + Gerber/drill zip
    prepare_jlcpcb_order.py runs note 25's final pre-order gate on
    candidate_2_fixed (headless Update-PCB-from-Schematic equivalent: 175/175
    netlist nodes in sync, zero rewrites needed; final DRC 0 hard errors;
    JLCPCB 4-layer capability checks) and exports the fabrication kit
    (kicad-cli Gerbers with Protel extensions + merged Excellon drill, 194
    holes verified, Edge.Cuts extents re-parsed at 110.00 x 110.00 mm),
    zipped byte-reproducibly to powder_doser_run3_candidate2_jlcpcb.zip for
    upload at https://cart.jlcpcb.com/quote. Note 25 + READMEs updated with
    the ordering block and order-form settings.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
    [powder_doser_run3_cand2-drl_map.gbr, powder_doser_run3_cand2.drl, powder_doser_run3_cand2.gbl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]
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2026-07-17 Fetch + commit Edison shunt-regulator-necessity artifacts; add note 26
    Edison LITERATURE_HIGH task b92d3e4f (status=success): verdict is that SR1
    is not strictly necessary for this low-inertia 12 V system but is cheap
    insurance; leaner replacement is bigger bulk cap + TVS; servo back-drive
    risk lives on the unprotected +5 V rail. Note 26 carries an editorial
    correction: Pololu #3776 is the 33.0 V / 4.00 ohm / 9 W set-point version.
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2026-07-17 Note 26 editorial: correct SR1 cost (Edison's ~$5 -> real $11.49 Pololu / $14.95 BOM-recorded)
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2026-11-03 claude-print: pass the Onshape keys so a print run can export the current part (#201)
    Without ONSHAPE_ACCESS_KEY and ONSHAPE_SECRET_KEY, Onshape answers 401 to
    STL export, tessellation and body requests, so the issue 197 run could not
    export the current Baseplate. Same repo secrets as claude.yml.
2026-11-07 Fixed-base multi-auger concepts: nose-to-nose pairs and an actuator tri-star (#204)
    Measures the current module's reach in front of the hinge from PR #170's
    STEP files, then places 2-3 copies and sweeps tilt with a mesh clearance
    check (2 mm) to size each concept:
    - A1: servos turned end for end (cases point back), shared base: 41 mm
    - A2: one gear + servo per module on opposite flanks: 37 mm
    - B1: gearless pair, Actuonix P16 under each plate: 37 mm
    - B2: gearless tri-star (3 at 120 deg): hinges 32 mm from the beaker axis
    - current modules on their own baseplates: 93 mm; three servo modules: 66 mm
    Adds the design note, the scripts that rebuild every number and figure,
    results.json and the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
2026-11-07 Multi-auger concepts: actuator mount section figure, servo clearance check (#204)
    Adds a half-section side view of a gearless module at 0, 45 and 90 deg
    showing the rod-end clevis, the rod through the shelf slot and the P16
    below, and moves the turned-servo clearance check into concepts.py
    (1.64 mm to the 28T gear at 40 deg, the same as today's layout).
2026-11-07 Multi-auger concepts: sweep B2 with the tapper on top; README wording (#204)
    Adds the all-three-at-90 deg case for the tri-star with the tap collar
    where it is today (56.5 mm, solenoid against the next tap collar) to the
    sweeps and results.json, and tightens a few README lines (footnote, the
    beaker for today's modules, the actuators' clearance to the balance).
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2026-11-10 Multi-auger B2: room under the tri-star and the stand it needs (#204)
    clearance.py measures, on the B2 + #203 tap bracket model, the lowest the
    doser gets over the beaker axis at every radius over 0-90 deg, how far the
    P16s hang below the shelf (208 mm, so the shelf needs a stand of at least
    217 mm) and the 188 mm column they leave under it. It tabulates the stand
    height some beakers and Erlenmeyers (with a funnel) need on a placeholder
    stir plate, and renders renders/b2_clearance.png.
2026-11-10 Multi-auger B2 clearance: stir plate among the actuators' lower ends; wide-neck note (#204)
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2026-11-14 Multi-auger B2 base: dimensioned drawing, smaller lobes to fit one H2D nozzle (#204)
    - renders/base_drawing.png: plan of the whole base, one lobe with every
    dimension, the tower profile and a tower pair from the front.
    - renders/base_iso.png: the base alone and with the three modules.
    - Lobes taper from 100 to 48 mm and end 174 mm from the beaker axis; the
    slot ends 112 mm behind the hinge (was 120). The base is 320.5 x 280.2 x
    52.25 mm, inside a single H2D nozzle's 325 x 320 mm.
    - Checks: modules 5.8 mm apart at the closest; moving parts to the base
    1.26 mm at 0 deg (plate notch to tower foot, as on today's doser), 4.1 mm
    from 5 deg; the P16 rod clears the shorter slot by 4.4 mm.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

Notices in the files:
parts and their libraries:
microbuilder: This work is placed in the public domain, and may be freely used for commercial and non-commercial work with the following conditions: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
